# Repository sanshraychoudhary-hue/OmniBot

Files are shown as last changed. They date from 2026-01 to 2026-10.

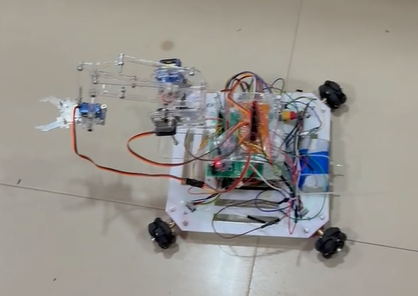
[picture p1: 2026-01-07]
assets/botimage.png

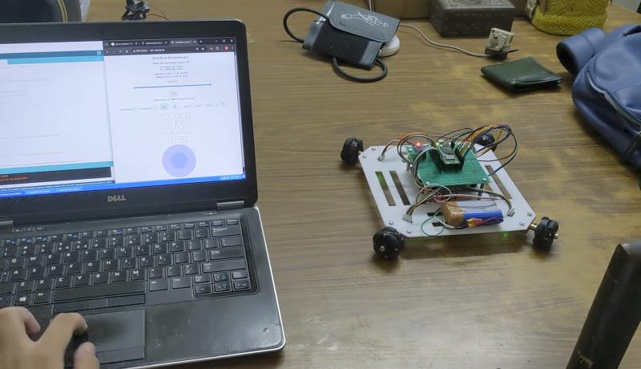
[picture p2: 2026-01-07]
assets/1.jpeg

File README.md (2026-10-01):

# OmniServe

**Project Title**: Design and Implementation of an Autonomous Holonomic Mobile Robot for Precision Warehouse Operations

## Overview
**OmniServe** is a Wi-Fi-controlled omni-directional robotic platform designed for enhanced mobility and object manipulation in constrained environments. It features precise movement using encoder feedback, a 3-DOF robotic arm for pick-and-place operations, and a web-based dashboard for real-time control, system monitoring, PID tuning, and vector-based motion commands. The robot can move in all eight directions and rotate in place, making it ideal for agile navigation. Using a PID algorithm, it achieves accurate linear movements with control over distance and direction. OmniServe is suitable for applications such as warehouse automation, smart delivery systems, and educational robotics.

This project was developed as part of a summer internship at **AICTE IDEA Lab, Guru Gobind Singh Indraprastha University**, from June 23, 2024, to August 1, 2024.

## Repository Structure
This repository contains all the design and source files for OmniServe, organized as follows:

*   **[`hardware/`](hardware/README.md)**: Specifications for motor drivers, encoders, RP2040, and wiring.
*   **[`code/`](code/README.md)**: Firmware for the Raspberry Pi Pico W (Arduino C++).
*   **[`design/`](design/README.md)**: Laser-cut chassis files (`.dxf`).
*   **[`UI/`](UI/README.md)**: Web Dashboard HTML/JS files.
*   **[`simulator_scripts/`](simulator_scripts/README.md)**: Python kinetics simulators.
*   **[`test_files/`](test_files/README.md)**: Unit tests for individual components.
*   **[`report/`](report/README.md)**: Full project report, presentation, and research.
*   **[`assets/`](assets/README.md)**: Images and demonstration videos.

---

## Features
*   **Omni-Directional Movement**: 360-degree movement in any direction, including rotation in place, enabled by omni-wheels.
*   **Encoder Feedback**: Real-time position and speed monitoring using quadrature encoders for precise control.
*   **PID Control**: Ensures accurate distance and direction travel, with tunable parameters via the dashboard.
*   **Web Dashboard**: Responsive interface for real-time control, telemetry display, and PID tuning. Supports joystick (using NippleJS) and keyboard (WASD) input.
*   **3-DOF Robotic Arm**: Servo-based arm for basic pick-and-place tasks, controlled via PWM signals.
*   **Emergency Stop**: Safety feature for immediate halt, implemented in both firmware and dashboard.
*   **Telemetry**: Live display of encoder values, robot state, and diagnostics on the dashboard.
*   **Vector-Based Commands**: Allows precise control over direction and distance.
*   **Expandable Design**: Ready for additional sensors like IMU or cameras.

### Feature Summary Table
| Feature | Description |
| :--- | :--- |
| **Omni-directional drive** | Move in any direction, rotate in place |
| **Encoder feedback** | Accurate distance and speed measurement |
| **PID control** | Precise movement and stopping |
| **Web dashboard** | Real-time control and monitoring |
| **Robotic arm** | 3-DOF, pick-and-place tasks |
| **Emergency stop** | Safety for users and environment |
| **Telemetry** | Live data on dashboard |
| **Expandable** | Add sensors and modules |

## Applications
*   **Warehouse Automation**: Material movement and inventory management in narrow aisles.
*   **Smart Delivery**: Last-mile delivery in controlled environments.
*   **Factory Logistics**: Transporting parts and tools.
*   **Educational Robotics**: Platform for teaching robotics, control systems, and programming.
*   **Prototyping**: Base for research and development in automation.

### Example Use Case: OmniServe in a Smart Warehouse
OmniServe can autonomously navigate narrow aisles, retrieve packages using its robotic arm, and deliver them to specified locations. Operators monitor via the dashboard and adjust PID parameters dynamically for varying payloads. It supports obstacle avoidance, route re-planning, and multi-robot collaboration.

## Hardware Architecture

### Chassis and Mechanical Design
*   **Four-wheel omni-wheel chassis** for 360-degree movement.
*   **Frame**: Lightweight aluminum for strength and portability.
*   **Omni-wheels**: 1.5-inch diameter for smooth lateral and diagonal movement.

### Motors and Drivers
*   **Motors**: Four DC motors, each with a magnetic quadrature encoder.
*   **Drivers**: Dual **TB6612FNG** motor drivers are used. Each driver controls two motors.
    *   **Driver 1 (Front)**: Controls Motor A (Front Left) and Motor B (Front Right).
    *   **Driver 2 (Rear)**: Controls Motor C (Rear Left) and Motor D (Rear Right).

### Encoders
*   **Quadrature encoders** (520 ticks/rev) on each wheel for closed-loop PID control and accurate distance estimation.

### Robotic Arm
*   **3-DOF servo-based arm** mounted on the chassis.
*   **Servos**: Standard hobby servos for base rotation, shoulder, and gripper movement.
*   **Capabilities**: Pick-and-place operations for objects up to 200g.

### Power Supply
*   Rechargeable **Li-ion battery pack** with voltage regulation for stable operation of logic and motors.

### Detailed Connection Diagram (GPIO Mapping)

#### Motor Driver 1 (Front Motors)
Controls the Front Left and Front Right wheels.
*   **Standby (STBY)**: GP8 (Shared)
*   **Channel A (Front Left - Motor A)**
    *   IN1: GP2
    *   IN2: GP3
    *   PWM: GP4
    *   *Encoder*: A (GP16), B (GP17)
*   **Channel B (Front Right - Motor B)**
    *   IN1: GP5
    *   IN2: GP6
    *   PWM: GP7
    *   *Encoder*: A (GP18), B (GP19)

#### Motor Driver 2 (Rear Motors)
Controls the Rear Left and Rear Right wheels.
*   **Standby (STBY)**: GP8 (Shared)
*   **Channel A (Rear Left - Motor C)**
    *   IN1: GP10
    *   IN2: GP11
    *   PWM: GP12
    *   *Encoder*: A (GP20), B (GP21)
*   **Channel B (Rear Right - Motor D)**
    *   IN1: GP13
    *   IN2: GP14
    *   PWM: GP15
    *   *Encoder*: A (GP22), B (GP26)

#### Other Connections
| Function | Pico W Pin(s) |
| :--- | :--- |
| **Standby** | GP8 |
| **Robotic Arm PWM** | GP23, GP24, GP25 (suggested) |
| **I2C (OLED/MPU)** | GP0 (SDA), GP1 (SCL) |

### Main Components Summary
| Module | Description |
| :--- | :--- |
| **Controller** | Raspberry Pi Pico W, runs main logic and hosts web dashboard |
| **Motor Drivers** | TB6612FNG, controls four DC motors |
| **Encoders** | Quadrature, provides feedback for PID control |
| **Robotic Arm** | 3-DOF, servo-based, for object manipulation |
| **Web Dashboard** | HTML/JS interface for control and monitoring |
| **Power Supply** | Li-ion battery, voltage regulation for stable operation |

### Design Choices and Trade-offs
*   **Omni-wheels** provide maximum maneuverability but require precise control logic.
*   **Raspberry Pi Pico W** selected for Wi-Fi capability and high GPIO count.
*   **Power management** ensures long operational time and safe charging.

## Software Architecture

### Embedded Firmware
*   Implemented in **Arduino C++** on Raspberry Pi Pico W.
*   Handles motor control, encoder feedback, PID computation, and dashboard communication.

### Web Dashboard
*   Responsive interface using **HTML, CSS, and JavaScript**.
*   Served directly from the Pico W.
*   **Features**: Joystick input (NippleJS), keyboard control (WASD), real-time telemetry, PID tuning.

### Communication Protocols
*   **WebSocket**: For low-latency, real-time control and telemetry.
*   **HTTP/REST**: For configuration and status queries.

### Control Logic
*   Supports direct (WASD) and vector-based movement.
*   Encoder feedback closes the loop for precise distance and direction.
*   PID controller tunable in real-time from the dashboard.

#### PID Implementation Example
```cpp
float error = target - measured;
integral += error * dt;
derivative = (error - prev_error) / dt;
output = Kp * error + Ki * integral + Kd * derivative;
prev_error = error;
```

### Encoder Handling
Interrupts are used for accurate tick counting at high speeds.

### Safety Features
Emergency stop validation for all commands.

## Methodology and Development Process
The project followed an iterative approach:
1.  **Design Phase**: Requirements analysis, block diagrams, and schematics.
2.  **Prototyping**: Breadboard testing of motors, encoders, and arm; 3D-printed parts.
3.  **Integration**: Full chassis assembly, wiring, and subsystem connection.
4.  **Testing and Validation**: Scenarios for movement, rotation, pick-and-place; accuracy checks.
5.  **Iterative Refinement**: Regular logging and addressing of issues.

### Project Timeline (Gantt Chart Overview)
Tasks were prioritized as Critical (Red), High (Orange), Medium (Yellow), Low (Blue):
*   Component Selection & BOM (Low)
*   Chassis Assembly & Wiring (Critical)
*   Motor & Power Integration (Critical)
*   Wi-Fi Setup & Web UI (Medium)
*   Encoder Calibration (High)
*   Motion Control (Critical)
*   PID Tuning & Distance Control (High)
*   Robotic Arm Mounting (High)
*   Pick-and-Place Logic (High)
*   Final Testing (Critical)
*   Documentation & Demo Video (Low)

Core functionality was built first, followed by precision control and arm integration.

## Results and Performance
*   **Movement Accuracy**: Average positional error <1 cm over 2 meters.
*   **Dashboard Latency**: <100 ms for responsive operation.
*   **Limitations**: Battery life under heavy load; occasional Wi-Fi dropouts in congested environments.

### Accuracy Table
| Target Distance (cm) | Measured (cm) | Error (cm) |
| :--- | :--- | :--- |
| 50 | 49.5 | 0.5 |
| 100 | 99.2 | 0.8 |
| 200 | 199.1 | 0.9 |

### Robotic Arm Performance
Successful pick-and-place for up to **200g** objects; repeatability within **2 mm**.

## Challenges and Solutions
| Challenge | Solution |
| :--- | :--- |
| **Omni-wheel control** | PID tuning, speed calibration |
| **Encoder noise** | Software debouncing, filtering |
| **Power management** | Separate power rails, voltage regulation |
| **Chassis alignment** | Precision assembly, iterative testing |
| **Servo mounting** | Custom 3D-printed brackets |
| **Real-time communication** | WebSocket optimization, error handling |
| **Dashboard responsiveness** | Efficient JS, minimal data transfer |
| **Subsystem integration** | Modular design, staged integration |
| **Testing in real environments** | Adaptive code, robust error handling |

## Future Work
*   **IMU Integration**: For angle feedback and stabilization.
*   **Camera and AI**: Object detection and visual navigation.
*   **Path Planning**: Autonomous navigation using map grids.
*   **Gripper Sensing**: Force or proximity sensors for delicate handling.
*   **Autonomous Object Sorting**: Algorithms for logistics applications.
*   **Research and Commercial Potential**: Platform for further development in warehouse automation, smart delivery, and education.

## Installation and Setup

### Hardware Setup
1.  Assemble the chassis with omni-wheels and mount the motors.
2.  Connect motor drivers (TB6612FNG) to the Raspberry Pi Pico W per GPIO mapping.
3.  Attach encoders to each wheel.
4.  Mount the 3-DOF robotic arm and connect servos.
5.  Wire the power supply with voltage regulation.
6.  Ensure all connections are secure and test for shorts.

### Software Setup
1.  Install Arduino IDE and add support for Raspberry Pi Pico.
2.  Upload the firmware (Arduino C++) from the `code/` directory to the Pico W.
3.  Host the web dashboard files on the Pico W (embedded in the code).
4.  Connect to the Pico W's Wi-Fi network.
5.  Access the dashboard via a web browser (e.g., `http://192.168.4.1` or the IP displayed on OLED).

### Dependencies
*   **Arduino C++** for firmware.
*   **HTML/CSS/JavaScript** for dashboard (NippleJS for joystick).
*   No additional package installations required beyond standard Arduino setup.

## Usage
1.  Power on the robot and connect to its Wi-Fi network.
2.  Open the web dashboard in a browser.
3.  Use **joystick** or **WASD keys** for movement.
4.  Tune **PID parameters** (Kp, Ki, Kd) via sliders.
5.  Control the **robotic arm** with dedicated buttons/sliders.
6.  Monitor **telemetry** (encoder values, speed, position).
7.  Activate **emergency stop** if needed.
8.  **Vector-based control**: Input direction (angle) and distance; the robot will execute precisely using PID.

## Contributors
*   **Alay Singh Negi**
*   **Kaustubh Singh Rautela**
*   **Shiven Pundir**
*   **Sanshray Choudhary**

*University School of Information, Communication & Technology (USIC&T), GGSIPU.*



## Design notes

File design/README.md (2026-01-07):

# Design Files

This directory contains the CAD and design files for the OmniBot chassis and manipulator arm.

## Files
*   `arm1plate.dxf`: Laser cutting file for the robotic arm base plate.
*   `designArm.dxf`: Laser cutting file for the arm structural components.

## Fabrication
These files are designed for laser cutting (typically Acrylic or MDF).

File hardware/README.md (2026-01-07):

# OmniBot Hardware Documentation

## Overview
The OmniBot is an autonomous holonomic mobile robot designed for precision warehouse operations. It uses a 4-wheel omnidirectional drive system (X-drive configuration) powered by a Raspberry Pi Pico W.

## Components List

### Microcontroller
*   **Raspberry Pi Pico W**: Dual-core ARM Cortex M0+ processor with built-in Wi-Fi. Handles all motor control, kinematics, sensor fusion, and web server for UI.

### Actuation & Drive
*   **Motors**: 4x DC Gear Motors with Magnetic Encoders (High precision for odometry).
*   **Motor Drivers**: 2x TB6612FNG Dual Motor Driver Carriers.
    *   *Note*: L298N was considered but TB6612FNG was chosen for better efficiency and compact size.
*   **Wheels**: 4x Omni-directional wheels (38mm diameter). The rollers allow sideways movement.

### Sensors
*   **Encoders**: 4x Incremental Quadrature Encoders (attached to motors) - 520 ticks/revolution.
*   **IMU**: MPU6050 (Accelerometer + Gyroscope) for orientation tracking (optional/integrated in some code versions).

### Interface
*   **Display**: OLED Display (0.96" 128x64 I2C) for status messages, IP address, and mode display.
*   **Joystick**: Analog Joystick (for manual control in some test setups).

## Pinout Configuration (Raspberry Pi Pico W)

| Component | Pin Function | Pico GP Pin |
| :--- | :--- | :--- |
| **Motor A (Front Left)** | IN1 | GP2 |
| | IN2 | GP3 |
| | PWM | GP4 |
| | Enc A | GP16 |
| | Enc B | GP17 |
| **Motor B (Front Right)** | IN1 | GP5 |
| | IN2 | GP6 |
| | PWM | GP7 |
| | Enc A | GP18 |
| | Enc B | GP19 |
| **Motor C (Rear Left)** | IN1 | GP10 |
| | IN2 | GP11 |
| | PWM | GP12 |
| | Enc A | GP20 |
| | Enc B | GP21 |
| **Motor D (Rear Right)** | IN1 | GP13 |
| | IN2 | GP14 |
| | PWM | GP15 |
| | Enc A | GP22 |
| | Enc B | GP26 |
| **Drivers** | STBY | GP8 |
| **I2C (Display/MPU)** | SDA | (Check Code) |
| | SCL | (Check Code) |

## Kinematics
The robot uses a 4-wheel X-configuration. The wheels are mounted at 45, 135, 225, and 315 degrees relative to the chassis frame.
*   **Wheel Angles**: [45°, 135°, 225°, 315°]
*   **Kinematic Model**: Allows calculation of individual wheel speeds based on desired Forward (Vx), Strafe (Vy), and Rotational (ω) velocities.

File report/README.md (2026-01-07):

# Project Report & Documentation

This directory contains the formal documentation, research resources, and presentation materials.

## Files
*   `omniBotReport.pdf`: The complete comprehensive project report.
*   `GeometricApproachtoInverseKinematics.pdf`: Reference paper for the 3-DOF arm implementation.
*   `presentation_outline.txt`: Outline used for the final presentation.
*   `research_and_resources.txt`: Notes on research topics (kinematics, components) and learning resources.
*   `canva_presentation_instructions.txt`: (Internal) Notes for slide creation.

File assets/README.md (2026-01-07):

# Project Assets

This folder contains media and visual assets for the OmniBot project.

## Contents
*   **Images**: Photos of the robot (`1.jpeg`), diagrams (`block diagram.png`, `softwareFlowchart.png`), and generated visualizations.
*   **Videos**: Demonstration videos of the robot in action (`Bot1.mp4`, `Bot2.mp4`, `OmniServe.mp4`).
*   **Graphics**: Logos and presentation materials.

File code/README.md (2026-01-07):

# OmniBot Code

This directory contains the firmware for the Raspberry Pi Pico W.

## Main Firmware
The active and most recent firmware version is located in the **`picoOmniCAR_latest_noMPU_oled_SavedWifi_P1`** directory.

### Features
*   **Omnidirectional Control**: Implements vector-based kinematics for holonomic movement.
*   **Wi-Fi Control**: Hosts a web server (or connects to one) to receive commands from the Web UI.
*   **PID Control**: (If applicable in this version) uses encoder feedback to maintain precise motor speeds.
*   **OLED Feedback**: Displays connection status, IP address, and current state.

## Legacy / Reference
*   `legacy_working_cursor.ino`: An older, known-working version of the code that supports cursor control and MPU6050 integration.

## Dependencies
This project is built using the Arduino IDE (with RP2040 core) or PlatformIO.
Required Libraries (install via Library Manager):
*   **Adafruit SSD1306** (for OLED)
*   **Adafruit GFX** (for OLED)
*   **Adafruit MPU6050** (if using MPU version)
*   **Adafruit Unified Sensor**
*   **WiFi** (Standard Pico W library)

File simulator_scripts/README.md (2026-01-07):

# Simulator Scripts

Python scripts for simulating the kinematics and behavior of the OmniBot.

## Files
*   `omni_bot_simulator.py`: Main simulation script.
*   `omni_sim.py`: Kinematics module used to calculate wheel ticks and trajectories.

## Requirements
*   Python 3.x
*   NumPy (`pip install numpy`)
*   Matplotlib (likely required for plotting in `omni_bot_simulator.py`)

## Usage
Run the simulator to visualize path planning and kinematic equations before deploying to the real robot.
```bash
python omni_bot_simulator.py
```

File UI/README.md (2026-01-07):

# Web UI

This directory contains the user interface for controlling the OmniBot.

## Files
*   `ui.html`: A standalone HTML/JS dashboard control panel.

## Usage
1.  Connect your device to the same Wi-Fi network as the OmniBot (or the OmniBot's Hotspot).
2.  Open `ui.html` in a modern web browser (Chrome, Firefox, Edge).
3.  Enter the IP address displayed on the OmniBot's OLED screen into the UI connection field.
4.  Use the on-screen joystick or buttons to control the robot.

## Features
*   **Virtual Joystick**: For omnidirectional manual control.
*   **Status Indicators**: Shows connection health.

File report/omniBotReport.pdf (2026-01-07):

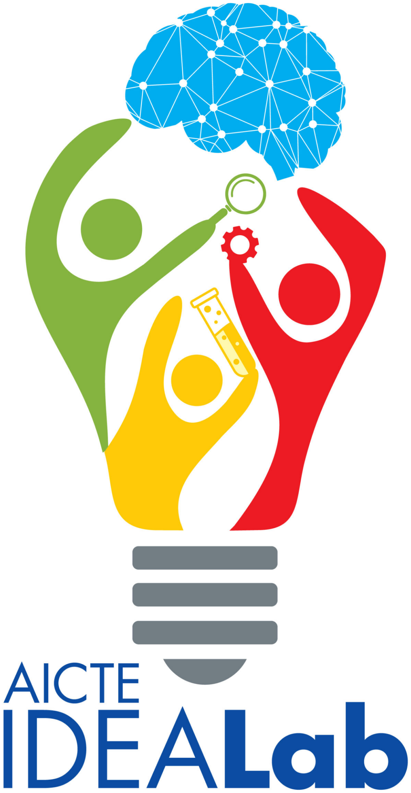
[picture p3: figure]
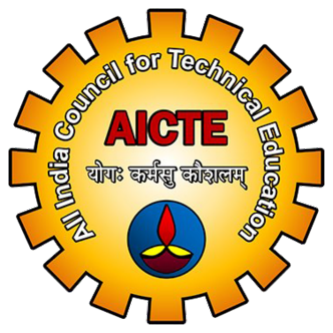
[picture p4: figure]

## Summer Internship Report

on

## OmniServe: Wi-Fi Controlled Omni-Directional Robot with Encoder Feedback and Pick-and-Place Arm

### Duration: June 23, 2024 to August 1, 2024

Under Supervision Of
Prof. Shiv Ram Meena
Mr. Saurabh Anand

Submitted By:
Alay Singh Negi 00916412823 Shiven Pundir 01716412823
Sanshray Choudhary 00816412823 Kaustubh Singh Rautela 00216412823 Jaideep 06416412823
Deependu Sharma 00616412823 Paras 05716412823
Divyansh 05916412823

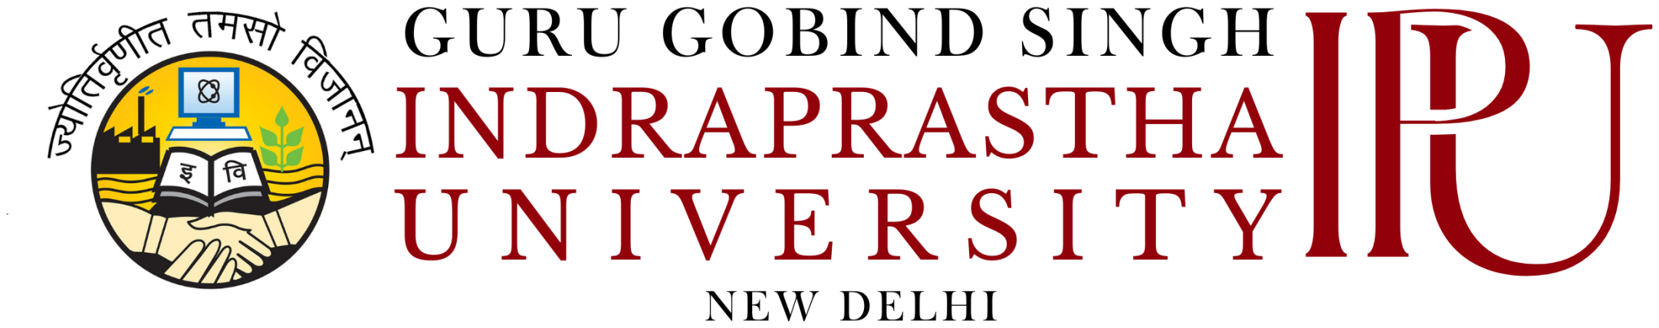
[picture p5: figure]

AICTE IDEA Lab-Guru Gobind Singh Indraprastha University E-Block, Guru Gobind Singh Indraprastha University Sector-16C, Dwarka, New Delhi - 110078 July 2024

### Certificate

This is to certify that the internship project entitled “OmniServe: Wi-Fi Controlled Omni-Directional Robot with Encoder Feedback and Pick-and-Place Arm” was successfully completed by the following students in partial fulfillment of the requirements for the award of the degree of Bachelor of Technology (ECE) under the internship program at AICTE IDEA Lab-Guru Gobind Singh Indraprastha University, New Delhi
- 110078.
1. Alay Singh Negi
2. Shiven Pundir
3. Sanshray Choudhary
4. Kaustubh Singh Rautela
5. Jaideep
6. Deependu
7. Paras
8. Divyansh
Mentor | Mentor

### Declaration

We hereby declare that the project work presented in this internship report entitled “OmniServe: Wi-Fi Controlled Omni-Directional Robot with Encoder Feedback and Pick-and-Place Arm” is entirely our own work and has not been submitted for any degree or diploma from this or any other institute for partial fulfillment of the requirements for the award of the degree of Bachelor of Technology (ECE).

1. Alay Singh Negi | USIC&T, GGSIPU
2. Shiven Pundir | USIC&T, GGSIPU
3. Sanshray Choudhary | USIC&T, GGSIPU
4. Kaustubh Singh Rautela | USIC&T, GGSIPU
5. Jaideep | USIC&T, GGSIPU
6. Deependu | USIC&T, GGSIPU
7. Paras | USIC&T, GGSIPU
8. Divyansh | USIC&T, GGSIPU

### Acknowledgment

We would like to express our sincere gratitude to the University School of Information, Communication & Technology, Guru Gobind Singh Indraprastha University for providing us with the valuable opportunity to participate in this internship program. Their constant encouragement and academic environment have played a vital role in our learning and professional development.
We are also deeply thankful to the AICTE IDEA Lab – Guru Gobind Singh Indraprastha University, located at E-Block, Sector 16C, Dwarka, New Delhi – 110078, for organizing the internship and enabling us to be part of such an enriching experience. The knowledge and hands-on exposure gained during this internship have been immensely beneficial to our growth.
A special note of thanks to our mentor, Prof. Shiv Ram Meena, for his unwavering support, insightful guidance, and constructive feedback throughout the project. His mentorship was instrumental in shaping our understanding and execution of this work.
We would also like to sincerely thank Ms. Heena Kalim, whose constant support and encouragement were crucial to our progress. Her sessions helped us understand a variety of tools and how to effectively use them in real-world applications. Her approachable nature and clarity in teaching made complex topics accessible and actionable.
Lastly, we extend our gratitude to all the faculty members whose teachings and support have contributed significantly to our academic journey.

### Abstract

This project presents OmniServe, a Wi-Fi-controlled, omni-directional robotic platform designed for enhanced mobility and object manipulation in constrained environments. The robot features precise movement capabilities using encoder feedback and a 3-DOF robotic arm for pick-and-place operations. It can move in all eight directions and rotate in place, enabling agile navigation. A web-based dashboard facilitates real-time control, system monitoring, PID tuning, and vector-based motion commands. Using a PID algorithm, the robot can perform accurate linear movements with control over both distance and direction. With its integrated robotic arm, OmniServe extends its utility to applications such as warehouse automation, smart delivery systems, and educational robotics.

# Contents

Introduction | 7
Literature Survey | 9
System Overview | 10
Hardware Architecture | 12
Software Architecture | 14
Methodology | 16
Features and Applications | 18
Results and Discussion | 20
Challenges Faced | 22
Future Work | 24
Conclusion | 25
1 Bibliography | 26

# Introduction

### Motivation

The rapid advancement of automation and robotics has revolutionized industries, logistics, and daily life. However, the need for versatile, precise, and remotely controllable robots remains a significant challenge, especially in constrained environments such as warehouses and smart factories. OmniServe was conceived to address these challenges by providing a robust, omni-directional robotic platform with advanced feedback and manipulation capabilities.

### Problem Statement

Traditional mobile robots are often limited by their drive mechanisms, restricting their movement to forward, backward, and simple turns. This limitation hinders their effectiveness in environments requiring agile navigation and precise positioning. Additionally, the lack of real-time feedback and manipulation capabilities further restricts their utility in complex tasks such as pick-and-place operations.

### Objectives

The primary objectives of the OmniServe project are:

- To design and develop a Wi-Fi controlled omni-directional robot capable of 360-degree movement.
- To implement encoder feedback for precise distance and direction control.
- To integrate a 3-DOF robotic arm for pick-and-place operations.
- To develop a web-based dashboard for real-time control, monitoring, and PID tuning.
- To demonstrate the robot’s applicability in warehouse automation, smart delivery, and educational robotics.

### Report Structure

This report is organized as follows:

- Literature Survey: Reviews related work and existing technologies in omni-directional robotics and feedback systems.
- System Overview: Provides a high-level description of the hardware and software components.
- Hardware and Software Architecture: Details the design and implementation of the robot’s physical and control systems.
- Methodology: Describes the development process, including design, prototyping, and testing.
- Features and Applications: Highlights the key features and potential use cases of OmniServe.
- Results and Discussion: Presents experimental results, performance analysis, and insights gained.
- Challenges Faced: Discusses obstacles encountered and solutions implemented.
- Future Work: Outlines possible enhancements and research directions.
- Conclusion: Summarizes the project outcomes and its significance.

# Literature Survey

### Omni-Directional Robots

Omni-directional robots have been widely researched for their ability to move in any direction without changing orientation, making them ideal for applications in constrained environments. Mecanum and omni-wheel designs are commonly used to achieve this mobility [1, 2].

### Encoder Feedback and PID Control

Precise movement in mobile robots is often achieved using quadrature encoders and PID (Proportional-Integral-Derivative) control algorithms. Encoder feedback allows for accurate distance and speed measurement, while PID controllers help maintain desired trajectories [3, 4].

### Robotic Arms and Manipulation

Robotic arms with multiple degrees of freedom (DOF) are essential for pick-and-place tasks. The integration of servo motors and inverse kinematics enables precise object manipulation [5, 6].

### Web-Based Control Systems

Recent advancements in IoT and embedded systems have enabled real-time robot control via web interfaces. Technologies such as WebSockets and REST APIs facilitate seamless communication between users and robots [7, 8].

### Summary

The literature indicates that combining omni-directional mobility, encoder feedback, PID control, and web-based interfaces can significantly enhance the versatility and usability of mobile robots in industrial and educational settings.

# System Overview

### System Architecture

OmniServe is designed as a modular, Wi-Fi controlled omni-directional robot with encoder feedback and a 3-DOF robotic arm. The system is divided into several subsystems: drive, feedback, control, and manipulation.

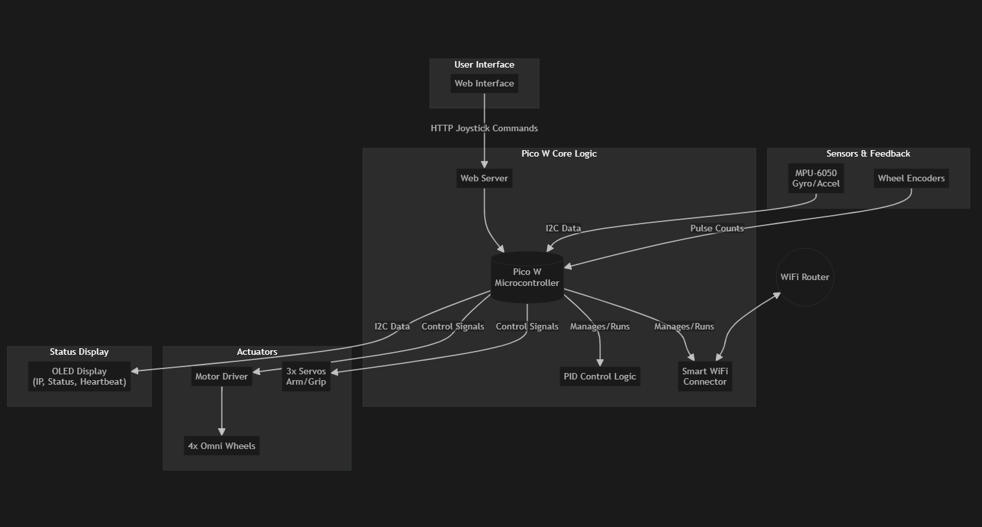
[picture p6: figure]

Figure 1: Block diagram of the OmniServe system.

### Main Components

- Controller: Raspberry Pi Pico W for main control and Wi-Fi communication.
- Motors: Four DC motors with omni-wheels for 360-degree movement.
- Motor Drivers: Dual TB6612FNG drivers for efficient motor control.
- Encoders: Quadrature encoders on each wheel for feedback.
- Robotic Arm: 3-DOF servo-based arm for pick-and-place tasks.
- Web Dashboard: Real-time control and monitoring interface.
- Power Supply: Battery pack with voltage regulation.

### Module Summary

Module | Description
Controller | Raspberry Pi Pico W, runs main logic and hosts web dashboard
Motor Drivers | TB6612FNG, controls four DC mo-tors
Encoders | Quadrature, provides feedback for PID control
Robotic Arm | 3-DOF, servo-based, for object ma-nipulation
Web Dashboard | HTML/JS interface for control and monitoring
Power Supply | Li-ion battery, voltage regulation for stable operation

### Interaction

The controller receives commands from the web dashboard, processes encoder feedback, and drives the motors accordingly. The robotic arm is controlled via PWM signals, and all telemetry is sent back to the dashboard for real-time monitoring.

# Hardware Architecture

### Chassis and Mechanical Design

The robot uses a four-wheel omni-wheel chassis, enabling movement in any direction. The frame is constructed from lightweight aluminum for strength and portability. The omni-wheels (1.5-inch diameter) allow for smooth lateral and diagonal movement.

### Motors and Drivers

Four DC motors are used, each controlled by a TB6612FNG dual motor driver. The drivers are chosen for their efficiency, compactness, and ability to handle the required current.

### Encoders

Each wheel is equipped with a quadrature encoder (520 ticks/rev) for precise feedback. The encoders are essential for closed-loop PID control and accurate distance estimation.

### Robotic Arm

A 3-DOF servo-based arm is mounted on the chassis. The arm uses standard hobby servos for base rotation, shoulder, and gripper movement, allowing for basic pick-and-place operations.

### Power Supply

A rechargeable Li-ion battery pack powers the system, with voltage regulation to ensure stable operation for both logic and motors.

### Wiring and Integration

All components are connected to the Raspberry Pi Pico W. Careful wiring and cable management ensure reliability and ease of maintenance.

### GPIO Mapping

Function | Pico W Pin(s)
Motor Control | GP2–GP15
Encoder Inputs | GP16–GP22, GP26
Standby | GP8
Robotic Arm PWM | GP23, GP24, GP25 (suggested)
I2C (reserved) | GP0 (SDA), GP1 (SCL)

### Hardware Photo

Figure 2: OmniServe hardware prototype.

### Design Choices and Trade-offs

The use of omni-wheels provides maximum maneuverability but requires careful control logic. The Raspberry Pi Pico W was selected for its Wi-Fi capability and GPIO count. Power management was a key consideration to ensure long operational time and safe charging.

# Software Architecture

### Embedded Firmware

The core logic is implemented in Arduino C++ and runs on the Raspberry Pi Pico W. The firmware handles motor control, encoder feedback, PID computation, and communication with the web dashboard.

### Web Dashboard

A responsive web dashboard (HTML, CSS, JavaScript) is served from the Pico W. It provides real-time control, telemetry, and PID tuning. Joystick input is handled using NippleJS, and all commands are sent via WebSockets.

### Communication Protocols

- WebSocket: For low-latency, real-time control and telemetry.
- HTTP/REST: For configuration and status queries.

### Control Logic

The robot supports both direct (WASD) and vector-based movement. Encoder feedback is used to close the loop for precise distance and direction control. The PID controller is tuned in real time from the dashboard.

### PID Implementation

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

### Encoder Handling

Interrupts are used to read quadrature encoder signals, ensuring accurate tick counting even at high speeds.

### Safety Features

An emergency stop is implemented in both firmware and dashboard. All commands are validated for safety before execution.

### Software Flowchart

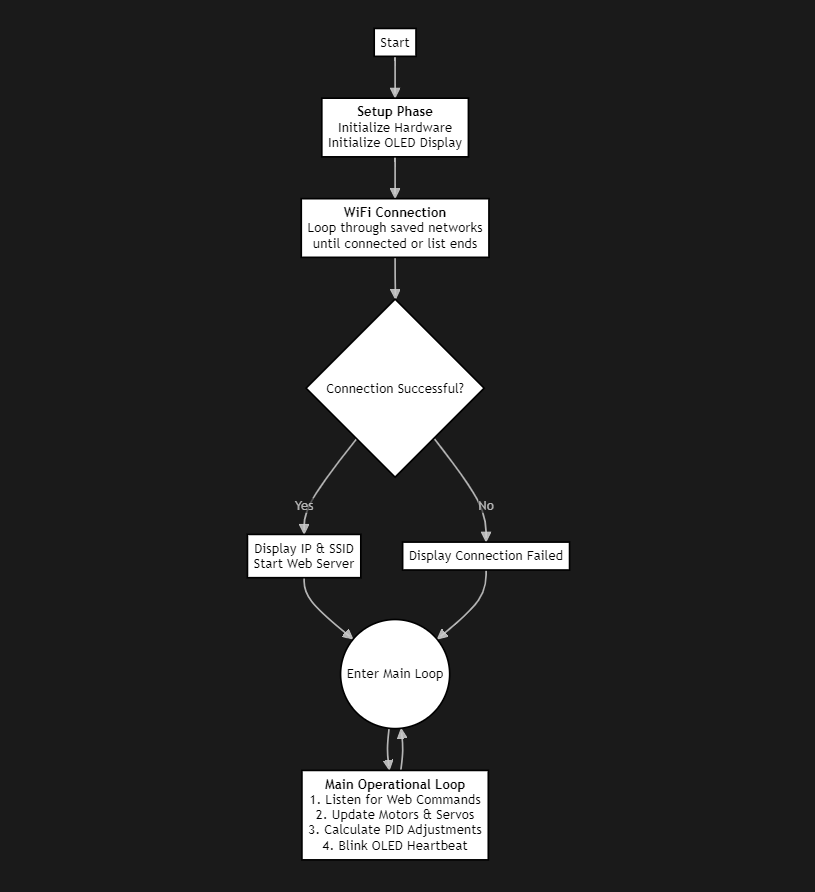
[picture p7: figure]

Figure 3: Software architecture flowchart.

# Methodology

### Design Phase

The project began with requirements analysis and system design. Block diagrams and schematics were created to plan the hardware and software integration.

### Prototyping

Initial prototypes were built using breadboards and 3D-printed parts. Motor drivers, encoders, and the robotic arm were tested individually before full integration.

### Integration

All subsystems were integrated on the main chassis. Careful attention was paid to wiring, power distribution, and signal integrity. The web dashboard was connected to the firmware for real-time control.

### Testing and Validation

The robot was tested in various scenarios: straight-line travel, diagonal movement, rotation, and pick-and-place tasks. Encoder feedback and PID control were validated for accuracy. The dashboard was tested for responsiveness and reliability.

### Iterative Development

Development followed an iterative approach, with regular testing and refinement. Issues were logged and addressed in each cycle.

### Gantt Chart

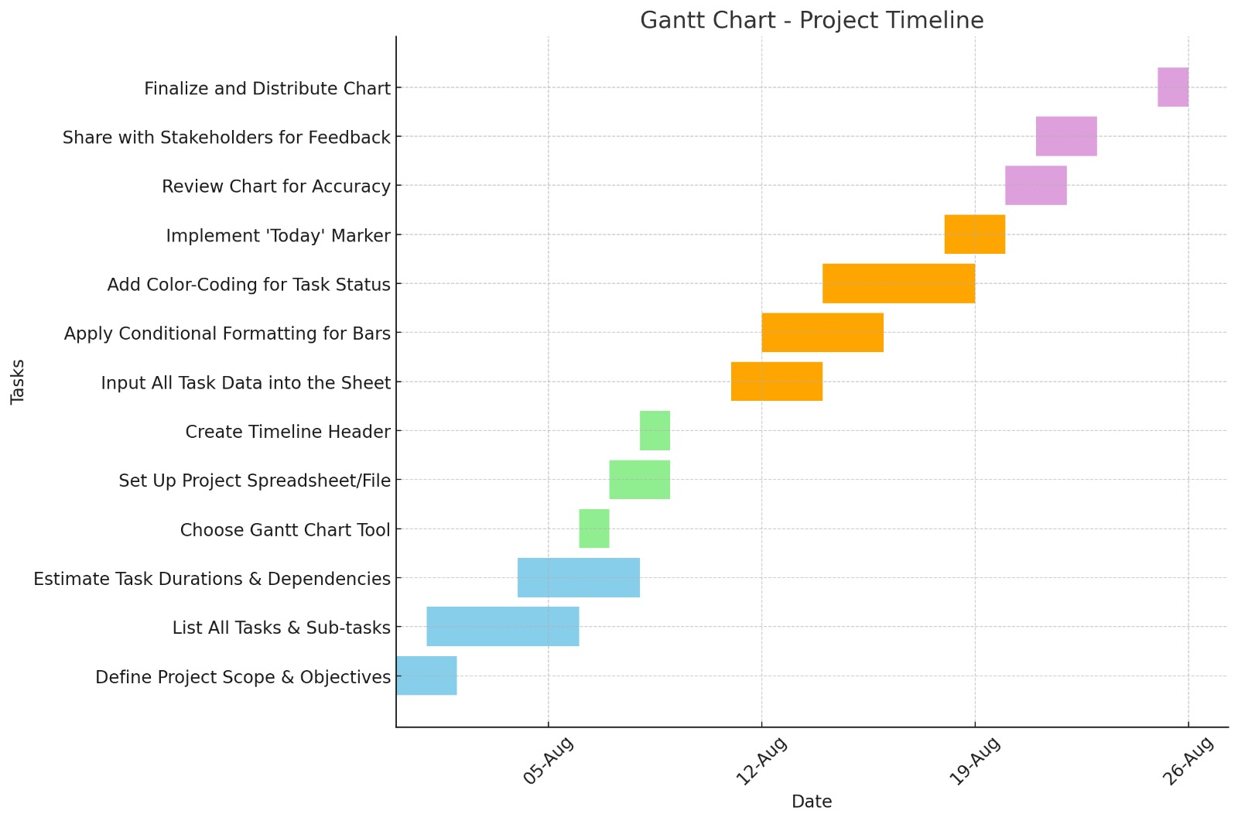
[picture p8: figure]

Figure 4: Project Gantt chart.

# Features and Applications

### Key Features

- Omni-Directional Movement: 360-degree movement in any direction, including rotation.
- Encoder Feedback: Real-time position and speed monitoring for precise control.
- PID Control: Ensures accurate distance and direction travel.
- Web Dashboard: Real-time control, telemetry, and PID tuning via Wi-Fi.
- Joystick and Keyboard Control: Supports both intuitive joystick and keyboard (WASD) input.
- 3-DOF Robotic Arm: Enables pick-and-place operations.
- Emergency Stop: Safety feature for immediate halt.
- Telemetry: Live display of encoder values, state, and diagnostics.
- Expandable: Ready for additional sensors (IMU, camera, etc.).

### Feature Summary

Feature | Description
Omni-directional drive | Move in any direction, rotate in place
Encoder feedback | Accurate distance and speed mea-surement
PID control | Precise movement and stopping
Web dashboard | Real-time control and monitoring
Robotic arm | 3-DOF, pick-and-place tasks
Emergency stop | Safety for users and environment
Telemetry | Live data on dashboard
Expandable | Add sensors and modules

### Applications

- Warehouse Automation: Material movement, inventory management.
- Smart Delivery: Last-mile delivery in controlled environments.
- Factory Logistics: Transporting parts and tools.
- Educational Robotics: Teaching robotics, control, and programming.
- Prototyping: Platform for research and development.

### Use-Case Scenario

Imagine a warehouse where OmniServe autonomously navigates aisles, picks up packages using its robotic arm, and delivers them to designated locations. The operator monitors and controls the robot remotely via the dashboard, adjusting PID parameters for optimal performance in real time.

# Results and Discussion

### Movement Accuracy

Experiments were conducted to evaluate the robot’s ability to travel set distances and angles. The encoder feedback and PID control enabled the robot to achieve an average positional error of less than 1 cm over 2 meters.

Table 4: Distance Travel Accuracy

Target Distance (cm) | Measured (cm) | Error (cm)
50 100 200 | 49.5 99.2 199.1 | 0.5 0.8 0.9

### Robotic Arm Performance

The 3-DOF arm successfully performed pick-and-place tasks with objects up to 200g. Repeatability tests showed consistent placement within 2 mm.

### Dashboard Latency

The web dashboard maintained a control latency below 100 ms, ensuring responsive operation.

### Figures


Figure 5: Test run of OmniServe .

### Discussion

The results demonstrate that OmniServe meets its design goals for mobility, precision, and manipulation. The main limitations observed were battery life under heavy load and occasional Wi-Fi dropouts in congested environments.

# Challenges Faced

### Technical Challenges

- Omni-Wheel Control: Achieving smooth, coordinated movement required careful tuning of motor speeds and PID parameters.
- Encoder Noise: Electrical noise caused false encoder readings, which were mitigated with software debouncing and filtering.
- Power Management: Balancing power between motors, servos, and logic circuits was critical to prevent brownouts.

### Hardware Challenges

- Chassis Alignment: Ensuring all wheels were perfectly aligned to avoid drift.
- Servo Mounting: Designing robust mounts for the robotic arm servos.

### Software Challenges

- Real-Time Communication: Maintaining low-latency, reliable Web-Socket connections.
- Dashboard Responsiveness: Optimizing the web interface for real-time updates.

### Integration and Testing

- Subsystem Integration: Combining hardware and software modules without conflicts.
- Testing in Real Environments: Adapting to Wi-Fi interference and variable lighting for the arm.

### Summary Table

Challenge | Solution
Omni-wheel control | PID tuning, speed calibration
Encoder noise | Software debouncing, filtering
Power management | Separate power rails, voltage regulation
Chassis alignment | Precision assembly, iterative testing
Servo mounting | Custom 3D-printed brackets
Real-time communica-tion | WebSocket optimization, error handling
Dashboard responsive-ness | Efficient JS, minimal data trans-fer
Subsystem integration | Modular design, staged integra-tion
Testing in real environ-ments | Adaptive code, robust error han-dling

# Future Work

### IMU Integration

Adding an inertial measurement unit (IMU) will enable angle feedback and stabilization, improving navigation and control.

### Camera and AI

Integrating a camera and AI module will allow for object detection, visual navigation, and advanced automation.

### Path Planning

Implementing path planning algorithms will enable the robot to autonomously navigate complex environments using map grids.

### Gripper Sensing

Upgrading the robotic arm with force or proximity sensors will improve pick-and-place reliability and enable delicate object handling.

### Autonomous Object Sorting

Developing algorithms for autonomous object sorting will expand the robot’s utility in logistics and manufacturing.

### Research and Commercial Potential

OmniServe can serve as a research platform for robotics and automation, and has potential for commercialization in warehouse automation, smart delivery, and educational robotics.

# Conclusion

OmniServe demonstrates the power of integrating omni-directional mobility, encoder feedback, PID control, and robotic manipulation into a single, Wi-Fi controlled platform. The project achieved its goals of precise movement, real-time control, and object interaction, validated through extensive testing and real-world scenarios.
The team gained valuable experience in embedded systems, robotics, software development, and teamwork. OmniServe’s modular design and open architecture make it a strong candidate for further research, educational use, and commercial deployment.
As robotics continues to transform industries, projects like OmniServe pave the way for smarter, more adaptable automation solutions. The knowledge and skills acquired will serve as a foundation for future innovation in robotics and automation.

# Bibliography

[1] M. Yim, W.-M. Shen, and B. Salemi, “Polybot: a modular reconfigurable robot,” Proceedings 2000 ICRA. Millennium Conference. IEEE International Conference on Robotics and Automation. Symposia Proceedings (Cat. No.00CH37065), pp. 514–520, 2000.
[2] B. E. Ilon, “Wheels for a course stable self-propelling vehicle moving in any desired direction on the ground,” US Patent 3876255, 1975.
[3] K. J. ˚Astr¨om and T. H¨agglund, PID Controllers: Theory, Design, and Tuning. Instrument Society of America, 1995.
[4] K. Ohnishi, “A new servo method in mechatronics,” IEEE Transactions on Industrial Electronics, vol. IE-34, no. 1, pp. 3–7, 1987.
[5] J. J. Craig, Introduction to Robotics: Mechanics and Control. Pearson Prentice Hall, 2005.
[6] B. Siciliano and O. Khatib, Springer Handbook of Robotics. Springer, 2010.
[7] A. Al-Fuqaha, M. Guizani, M. Mohammadi, M. Aledhari, and
M. Ayyash, “Internet of things: A survey on enabling technologies, protocols, and applications,” IEEE Communications Surveys Tutorials, vol. 17, no. 4, pp. 2347–2376, 2015.
[8] I. Lee and K. Lee, “The internet of things (iot): Applications, investments, and challenges for enterprises,” Business Horizons, vol. 58, no. 4, pp. 431–440, 2013.

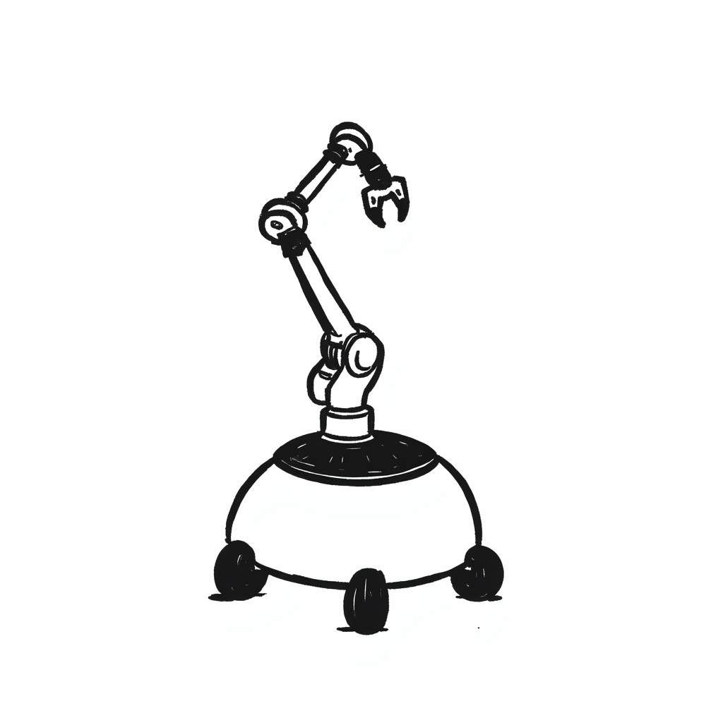
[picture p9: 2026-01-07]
assets/KWLnM13xIoRA6nbylS85tfKQQ0C2_images_a omnidirectional robot with pick and place robotic arm_ink-drawing-v2_0_1754448395945_ypl95d_1_generation.png

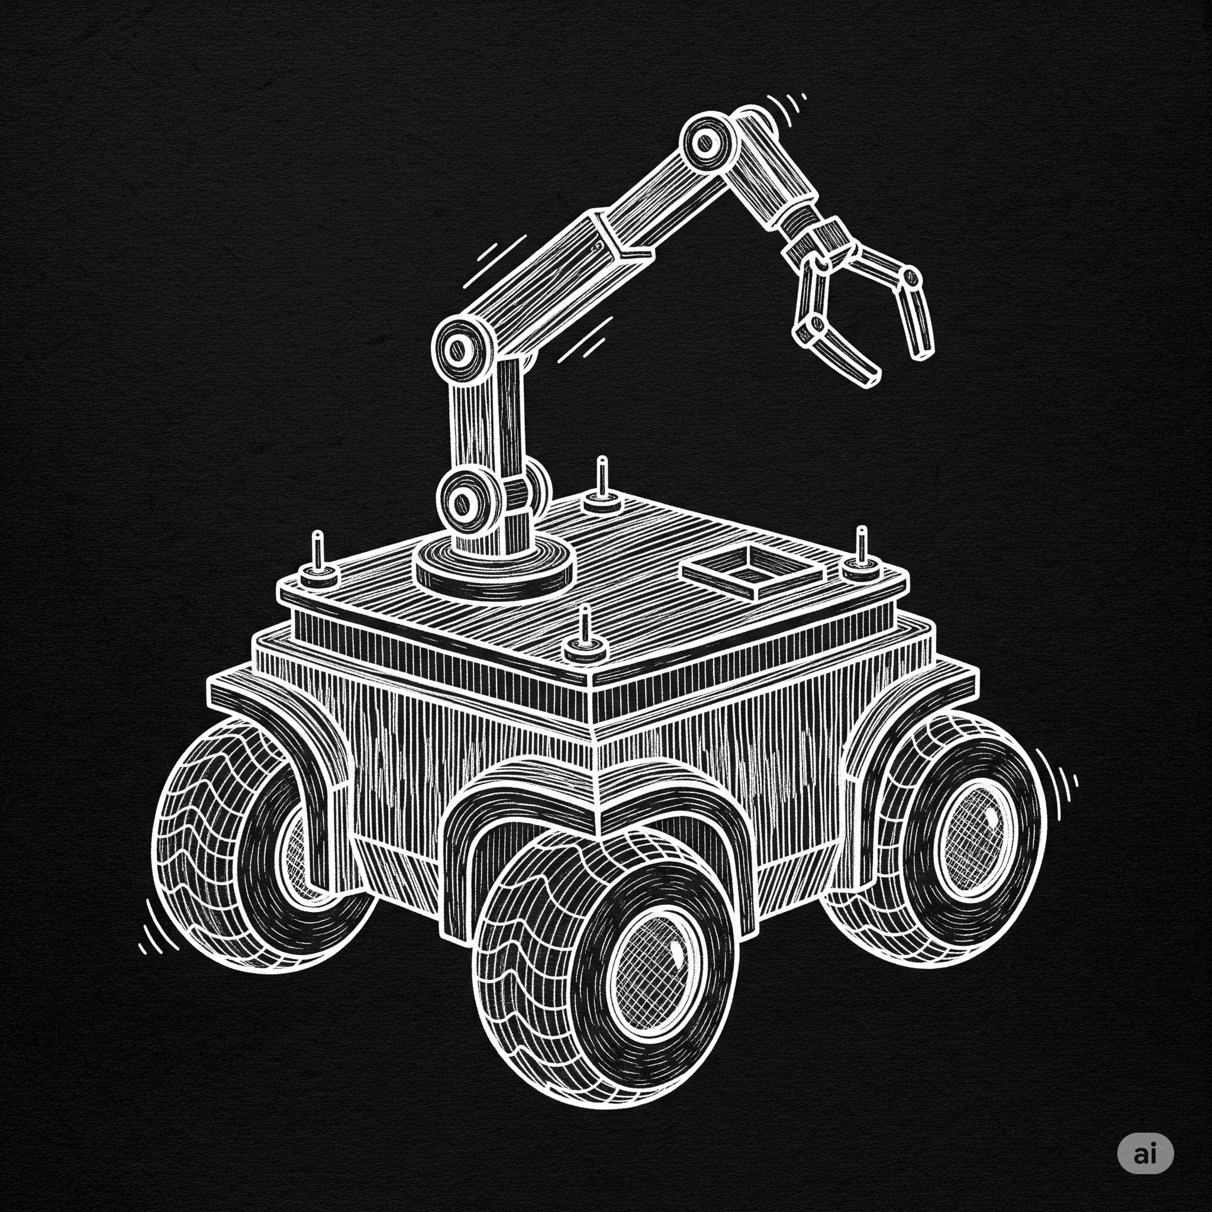
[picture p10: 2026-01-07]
assets/Gemini_Generated_Image_fljk0ffljk0ffljk.png

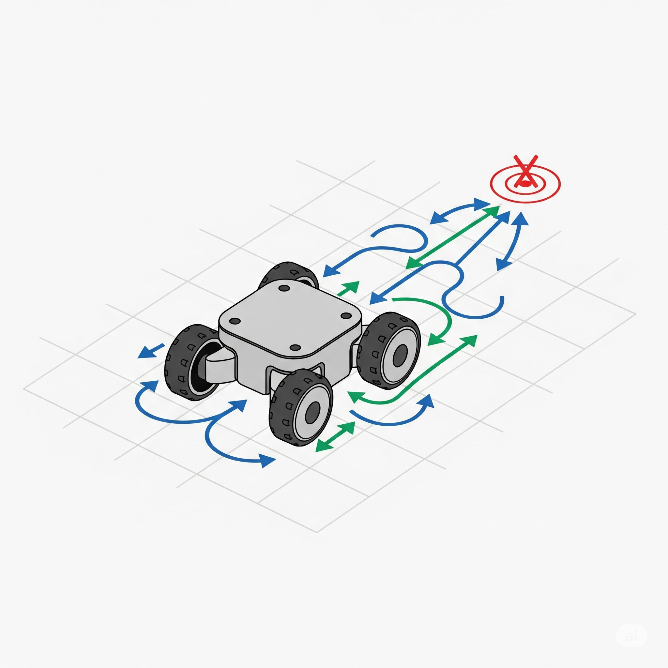
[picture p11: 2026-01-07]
assets/Gemini_Generated_Image_u47356u47356u473.png

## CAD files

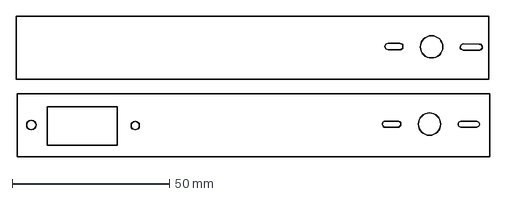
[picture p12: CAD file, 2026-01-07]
design/designArm.dxf
150.3 x 44.6 mm

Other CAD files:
design/arm1plate.dxf

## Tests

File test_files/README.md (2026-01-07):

# Test Files

This directory contains individual unit test sketches used to debug and verify specific hardware components before full integration.

## Files
*   **picoEncoderTest**: Verifies that the motor encoders are counting ticks correctly.
*   **picoMotorTest**: Tests basic motor rotation (Forward/Backward) to check driver wiring.
*   **picoDisplayTest**: Tests the OLED screen connection and library.
*   **picoMPU_test**: Reads raw data from the MPU6050 accelerometer/gyroscope.
*   **picoServoTest / picoServoTestWifi**: Tests servo motor control for the arm.
*   **picoWifiTester**: Verifies Wi-Fi connectivity on the Pico W.
*   **picoLed**: Simple blink test.

## Usage
Upload these sketches individually to isolate issues with specific components.

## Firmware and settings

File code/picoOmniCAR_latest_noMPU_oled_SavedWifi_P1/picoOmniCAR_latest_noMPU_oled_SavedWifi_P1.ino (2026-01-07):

/**********************************************************
 *                    PIN CONNECTIONS                     *
 **********************************************************

 Wi-Fi Control Bot with 4 Motors & 8 Encoder Inputs
 Controller: Raspberry Pi Pico W
 Motor Drivers: 2 x TB6612FNG (4 motors total)

 ------------------- MOTOR CONNECTIONS --------------------

 Motor A (Front Left):
   AIN1  -> GP2
   AIN2  -> GP3
   PWMA  -> GP4

 Motor B (Front Right):
   BIN1  -> GP5
   BIN2  -> GP6
   PWMB  -> GP7

 Motor C (Rear Left):
   CIN1  -> GP10
   CIN2  -> GP11
   PWMC  -> GP12

 Motor D (Rear Right):
   DIN1  -> GP13
   DIN2  -> GP14
   PWMD  -> GP15

 STBY (Standby for both drivers): 
   STBY  -> GP8

 ------------------- ENCODER CONNECTIONS ------------------

 Front Left Encoder (Motor A):
   Channel A -> GP16 (FL_ENC_A)
   Channel B -> GP17 (FL_ENC_B)

 Front Right Encoder (Motor B):
   Channel A -> GP18 (FR_ENC_A)
   Channel B -> GP19 (FR_ENC_B)

 Rear Left Encoder (Motor C):
   Channel A -> GP20 (RL_ENC_A)
   Channel B -> GP21 (RL_ENC_B)

 Rear Right Encoder (Motor D):
   Channel A -> GP22 (RR_ENC_A)
   Channel B -> GP26 (RR_ENC_B)

------------------- WHEEL SPECS ------------------
DIA = 1.5 inch
Ticks per revoultion = 520

------------------- PCB/WIRING INFO ------------------
A-B A-B A-B A-B PWM-B-A PWM-B-A PWM-B-A PWM-B-A

-------------------SERVO INFO ------------------
Base: GP9
Left Hand: GP8
Right Hand: GP27
Gripper: GP28

**********************************************************/

#include <WiFi.h>

#include <Servo.h>

#include <Wire.h>
#include <Adafruit_GFX.h>
#include <Adafruit_SH110X.h>


// Wi-Fi credentials structure
struct WiFiNetwork {
  const char* ssid;
  const char* password;
};

// List of known networks
WiFiNetwork knownNetworks[] = {
  {"SurPoon", "gogetsomehelpfromgod1234"},
  {"IDEA LAB_2.4G", "ggsipu@321"}
  };

const int numNetworks = sizeof(knownNetworks) / sizeof(knownNetworks[0]);


// Wi-Fi credentials
//const char* ssid = "SurPoon";
//const char* password = "gogetsomehelpfromgod1234";

// OLED Display for SH1106
#define OLED_I2C_ADDRESS 0x3C
#define DISPLAY_WIDTH 128
#define DISPLAY_HEIGHT 64
#define OLED_RESET -1
//#define OLED_SDA 16
//#define OLED_SCL 17
Adafruit_SH1106G display = Adafruit_SH1106G(DISPLAY_WIDTH, DISPLAY_HEIGHT, &Wire, OLED_RESET);

// -- Heartbeat Globals --
unsigned long lastHeartbeatMillis = 0;
bool heartbeatState = false;

// Wi-Fi Credentials
//const char* ssid = "IDEA LAB_2.4G";
//const char* password = "ggsipu@321";

// Motor A (Front Left)
#define AIN1 2
#define AIN2 3
#define PWMA 4

// Motor B (Front Right)
#define BIN1 6  // changed from 6 to 0
#define BIN2 5
#define PWMB 7  // changed from 7 to 1

// Motor C (Rear Left)--- swapped for direction change
#define CIN1 10
#define CIN2 11
#define PWMC 12

// Motor D (Rear Right)--- swapped for direction change
#define DIN1 14
#define DIN2 13
#define PWMD 15

//#define STBY 8
//#define LED_PIN 25



// --------- Encoder Pin Definitions ---------
#define FL_ENC_A 0 // 16
#define FL_ENC_B 1 // 17
#define FR_ENC_A 19
#define FR_ENC_B 18
#define RL_ENC_A 22
#define RL_ENC_B 26
#define RR_ENC_A 21
#define RR_ENC_B 20

// --------- Encoder Tick Counters (Signed) ---------
volatile long ticksFL = 0;
volatile long ticksFR = 0;
volatile long ticksRL = 0;
volatile long ticksRR = 0;

// --- Per-Wheel PID & Movement Control ---
struct WheelPID {
float Kp = 1.0, Ki = 0.0, Kd = 0.0;
  float integral = 0;
  float last_error = 0;
  long start_ticks = 0;
  long target_ticks = 0;
  bool active = false;
};

WheelPID pidFL, pidFR, pidRL, pidRR;
bool move_active = false;

//Wheel-Dimensions Globals
float wheel_diameter_cm = 3.81;  // 1.5 inch in cm
int encoder_ticks_per_rev = 520;
float total_distance_cm = 0;
int last_ticks_sum = 0;
int current_angle = 0;


// --------- Encoder ISRs with Direction Detection ---------
void encFL_ISR() {
  if (digitalRead(FL_ENC_A) == digitalRead(FL_ENC_B))
    ticksFL++;
  else
    ticksFL--;
}

void encFR_ISR() {
  if (digitalRead(FR_ENC_A) == digitalRead(FR_ENC_B))
    ticksFR++;
  else
    ticksFR--;
}

void encRL_ISR() {
  if (digitalRead(RL_ENC_A) == digitalRead(RL_ENC_B))
    ticksRL++;
  else
    ticksRL--;
}

void encRR_ISR() {
  if (digitalRead(RR_ENC_A) == digitalRead(RR_ENC_B))
    ticksRR++;
  else
    ticksRR--;
}


WiFiServer server(80);
int speedVal = 200;
String currentState = "Stopped";

Servo servoBase, servoLeft, servoRight, servoGrip;

void setup() {
  Serial.begin(115200);

  // OLED Display Setup
  //Wire.setSDA(OLED_SDA);
  //Wire.setSCL(OLED_SCL);
  //Wire.begin();
  
  if(!display.begin(OLED_I2C_ADDRESS, true)) {
    Serial.println(F("SH1106 allocation failed"));
  } else {
    display.clearDisplay();
    display.setTextSize(2);
    display.setTextColor(SH110X_WHITE);
    display.setCursor(0, 10);
    display.println("Searching...");
    display.display();
  }

  // Setup motor control pins
  pinMode(AIN1, OUTPUT); pinMode(AIN2, OUTPUT); pinMode(PWMA, OUTPUT);
  pinMode(BIN1, OUTPUT); pinMode(BIN2, OUTPUT); pinMode(PWMB, OUTPUT);
  pinMode(CIN1, OUTPUT); pinMode(CIN2, OUTPUT); pinMode(PWMC, OUTPUT);
  pinMode(DIN1, OUTPUT); pinMode(DIN2, OUTPUT); pinMode(PWMD, OUTPUT);
//  pinMode(STBY, OUTPUT); digitalWrite(STBY, HIGH);
  pinMode(LED_BUILTIN, OUTPUT);

 // Encoder Pins as Input
pinMode(FL_ENC_A, INPUT_PULLUP); pinMode(FL_ENC_B, INPUT_PULLUP);
pinMode(FR_ENC_A, INPUT_PULLUP); pinMode(FR_ENC_B, INPUT_PULLUP);
pinMode(RL_ENC_A, INPUT_PULLUP); pinMode(RL_ENC_B, INPUT_PULLUP);
pinMode(RR_ENC_A, INPUT_PULLUP); pinMode(RR_ENC_B, INPUT_PULLUP);

// Attach interrupts to Channel A of each encoder
attachInterrupt(digitalPinToInterrupt(FL_ENC_A), encFL_ISR, RISING);
attachInterrupt(digitalPinToInterrupt(FR_ENC_A), encFR_ISR, RISING);
attachInterrupt(digitalPinToInterrupt(RL_ENC_A), encRL_ISR, RISING);
attachInterrupt(digitalPinToInterrupt(RR_ENC_A), encRR_ISR, RISING);

  // Attach servos to their GPIO pins
  servoBase.attach(9);
  servoLeft.attach(8);
  servoRight.attach(27);
  servoGrip.attach(28);

  // --- Smart WiFi Connection ---
  bool connected = false;
  for (int i = 0; i < numNetworks; i++) {
    // Update display to show current attempt
    display.clearDisplay();
    display.setTextSize(1);
    display.setCursor(0, 10);
    display.println("Trying:");
    display.setTextSize(2);
    display.setCursor(0, 25);
    display.println(knownNetworks[i].ssid);
    display.display();
    
    WiFi.begin(knownNetworks[i].ssid, knownNetworks[i].password);
    Serial.print("\nAttempting to connect to ");
    Serial.println(knownNetworks[i].ssid);

    // Wait for connection with a 7-second timeout
    unsigned long startAttemptTime = millis();
    while (WiFi.status() != WL_CONNECTED && millis() - startAttemptTime < 7000) {
      delay(500);
      Serial.print(".");
    }

    // If connected, break the loop
    if (WiFi.status() == WL_CONNECTED) {
      connected = true;
      break;
    } else {
      Serial.println("\nFailed to connect.");
      WiFi.disconnect(true); // Disconnect and try next network
      delay(100);
    }
  }

  // Final status update on display
  display.clearDisplay();
  display.setCursor(0,0);
  if (connected) {
    Serial.println("\nWiFi connected.");
    Serial.print("IP address: "); Serial.println(WiFi.localIP());
    Serial.print("SSID: "); Serial.println(WiFi.SSID());
    
    display.setTextSize(2);
    display.println("Connected!");
    display.setTextSize(1);
    display.setCursor(0, 20);
    display.print("IP: ");
    display.println(WiFi.localIP());
    display.setCursor(0, 32);
    display.print("SSID: ");
    display.println(WiFi.SSID());
  } else {
    Serial.println("\nCould not connect to any WiFi network.");
    display.setTextSize(2);
    display.println("Connection");
    display.println("Failed");
  }
  display.display();


  // Connect to Wi-Fi
  // WiFi.begin(ssid, password);
  // while (WiFi.status() != WL_CONNECTED) {
  //   delay(500); Serial.print(".");
  //   display.print(".");
  //   display.display();
  // }

  // Serial.println("\nWiFi connected.");
  // Serial.print("IP address: "); Serial.println(WiFi.localIP());

  // // Update OLED
  // display.clearDisplay();
  // display.setCursor(0,0);
  // display.setTextSize(2);
  // display.println("Connected!");
  // display.setTextSize(1);
  // display.setCursor(0, 20);
  // display.print("IP Address:");
  // display.setCursor(0, 30);
  // display.print(WiFi.localIP());
  // display.display();

  server.begin();
}

void loop() {
  // --- OLED Heartbeat ---
  // Toggles a pixel in the top-right corner to show the Pico is running.
  if (millis() - lastHeartbeatMillis > 500) {
    lastHeartbeatMillis = millis();
    heartbeatState = !heartbeatState;
    display.fillRect(DISPLAY_WIDTH - 3, 0, 3, 3, heartbeatState ? SH110X_WHITE : SH110X_BLACK);
    display.display();
  }
  
  WiFiClient client = server.available();
  updateDistanceMoved();

  if (move_active) {
    updateAllWheelPIDs();
}

  if (client) {
    Serial.println("\nClient connected");

    String request = client.readStringUntil('\r');
    client.flush();
    Serial.print("Request: "); Serial.println(request);

    if (request.indexOf("/servo?") != -1) {
      if (request.indexOf("base=") != -1) {
        int val = request.substring(request.indexOf("base=") + 5).toInt();
        servoBase.write(constrain(val, 0, 180));
      } else if (request.indexOf("left=") != -1) {
        int val = request.substring(request.indexOf("left=") + 5).toInt();
        servoLeft.write(constrain(val, 0, 120));
      } else if (request.indexOf("right=") != -1) {
        int val = request.substring(request.indexOf("right=") + 6).toInt();
        servoRight.write(constrain(val, 70, 180));
      } else if (request.indexOf("grip=") != -1) {
        int val = request.substring(request.indexOf("grip=") + 5).toInt();
        servoGrip.write(constrain(val, 0, 120));
      }
      client.println("HTTP/1.1 200 OK");
      client.println("Content-Type: text/plain");
      client.println();
      client.print("OK");
      return;
    }
    else if (request.indexOf("/move_rt?") != -1) {
      float dist = request.substring(request.indexOf("dist=") + 5, request.indexOf("&")).toFloat();
      float angle = request.substring(request.indexOf("angle=") + 6).toFloat();
      startMoveRT(dist, angle);
    }
    else if (request.indexOf("/move_xy?") != -1) {
      float x = request.substring(request.indexOf("x=") + 2, request.indexOf("&")).toFloat();
      float y = request.substring(request.indexOf("y=") + 2).toFloat();
      startMoveXY(x, y);
    }
    else if (request.indexOf("/stop_all_move") != -1) {
      stopAllMove();
    }
    else if (request.indexOf("/set_pid?") != -1) {
       // Example: /set_pid?wheel=fl&p=1.2&i=0.1&d=0.3
      String wheel = request.substring(request.indexOf("wheel=") + 6, request.indexOf("&"));
      float p = request.substring(request.indexOf("p=") + 2, request.indexOf("&", request.indexOf("p="))).toFloat();
      float i = request.substring(request.indexOf("i=") + 2, request.indexOf("&", request.indexOf("i="))).toFloat();
      float d = request.substring(request.indexOf("d=") + 2).toFloat();
      
      if (wheel == "fl") { pidFL.Kp = p; pidFL.Ki = i; pidFL.Kd = d; }
      else if (wheel == "fr") { pidFR.Kp = p; pidFR.Ki = i; pidFR.Kd = d; }
      else if (wheel == "rl") { pidRL.Kp = p; pidRL.Ki = i; pidRL.Kd = d; }
      else if (wheel == "rr") { pidRR.Kp = p; pidRR.Ki = i; pidRR.Kd = d; }
    }
    else if (request.indexOf("/vector") != -1) {
      int angleStart = request.indexOf("angle=") + 6;
int forceStart = request.indexOf("force=") + 6;
int ampIndex = request.indexOf('&');

int angle = 0;
float force = 0;

if (angleStart > 5 && forceStart > 5) {
  if (angleStart < forceStart) {
    angle = request.substring(angleStart, ampIndex).toInt();
    force = request.substring(forceStart).toFloat();
  } else {
    force = request.substring(forceStart, ampIndex).toFloat();
    angle = request.substring(angleStart).toInt();
  }
}


      int dynamicSpeed = int(constrain(force * 255, 0, 255));
      handleAnalogDirection(angle, dynamicSpeed);
    }
    else if (request.indexOf("/FL") != -1) moveForwardLeft(speedVal);
    else if (request.indexOf("/FR") != -1) moveForwardRight(speedVal);
    else if (request.indexOf("/F") != -1) moveForward(speedVal);
    else if (request.indexOf("/BL") != -1) moveBackwardLeft(speedVal);
    else if (request.indexOf("/BR") != -1) moveBackwardRight(speedVal);
    else if (request.indexOf("/CW") != -1) rotateCW(speedVal);
    else if (request.indexOf("/CCW") != -1) rotateCCW(speedVal);
    else if (request.indexOf("/B") != -1) moveBackward(speedVal);
    else if (request.indexOf("/L") != -1) moveLeft(speedVal);
    else if (request.indexOf("/R") != -1) moveRight(speedVal);
    else if (request.indexOf("/S") != -1) stopBot();
    else if (request.indexOf("/reset_encoders") != -1) {
      ticksFL = 0;
      ticksFR = 0;
      ticksRL = 0;
      ticksRR = 0;
      Serial.println("Encoders reset.");
    }

    else if (request.indexOf("/speed=") != -1) {
      int val = request.substring(request.indexOf('=') + 1).toInt();
      speedVal = constrain(val, 0, 255);
      Serial.print("Speed set to: "); Serial.println(speedVal);
    }
    else if (request.indexOf("/reset_distance") != -1) {
      total_distance_cm = 0;
      last_ticks_sum = abs(ticksFL) + abs(ticksFR) + abs(ticksRL) + abs(ticksRR);
      Serial.println("Distance reset.");
    }
    else if (request.indexOf("/status") != -1) {
      
      client.println("HTTP/1.1 200 OK");
      client.println("Content-Type: application/json");
      client.println();
      client.print("{"
  "\"state\":\"" + currentState + "\","
  "\"speed\":" + String(speedVal) + ","
  "\"fl\":" + String(ticksFL) + ","
  "\"fr\":" + String(ticksFR) + ","
  "\"rl\":" + String(ticksRL) + ","
  "\"rr\":" + String(ticksRR) + ","
  "\"angle\":" + String(current_angle) + ","
  "\"distance\":" + String(total_distance_cm, 2) +
"}");


      return;
    }

    client.println("HTTP/1.1 200 OK");
    client.println("Content-type:text/html\r\n\r\n");
    sendWebPage(client);
  }
}



void blinkLED() {
  digitalWrite(LED_BUILTIN, HIGH);
  delay(50);
  digitalWrite(LED_BUILTIN, LOW);
}

// Move Forward: Bot moves straight ahead ↑
// A (FL), B (FR), C (RL), D (RR) => All Forward
void moveForward(int spd) {
  currentState = "Moving Forward";
  Serial.println(currentState);

  // Motor A (Front Left)
  digitalWrite(AIN1, HIGH); digitalWrite(AIN2, LOW); analogWrite(PWMA, spd);

  // Motor B (Front Right)
  digitalWrite(BIN1, HIGH); digitalWrite(BIN2, LOW); analogWrite(PWMB, spd);

  // Motor C (Rear Left)
  digitalWrite(CIN1, HIGH); digitalWrite(CIN2, LOW); analogWrite(PWMC, spd);

  // Motor D (Rear Right)
  digitalWrite(DIN1, HIGH); digitalWrite(DIN2, LOW); analogWrite(PWMD, spd);

  blinkLED();
}

// Move Backward: Bot moves straight backward ↓
// A, B, C, D => All Backward
void moveBackward(int spd) {
  currentState = "Moving Backward";
  Serial.println(currentState);

  // Motor A (Front Left)
  digitalWrite(AIN1, LOW); digitalWrite(AIN2, HIGH); analogWrite(PWMA, spd);

  // Motor B (Front Right)
  digitalWrite(BIN1, LOW); digitalWrite(BIN2, HIGH); analogWrite(PWMB, spd);

  // Motor C (Rear Left)
  digitalWrite(CIN1, LOW); digitalWrite(CIN2, HIGH); analogWrite(PWMC, spd);

  // Motor D (Rear Right)
  digitalWrite(DIN1, LOW); digitalWrite(DIN2, HIGH); analogWrite(PWMD, spd);

  blinkLED();
}

// Move Left: Bot strafes left ←
// A (FL) & D (RR) => Backward
// B (FR) & C (RL) => Forward
void moveLeft(int spd) {
  currentState = "Moving Left";
  Serial.println(currentState);

  // Motor A (Front Left)
  digitalWrite(AIN1, LOW); digitalWrite(AIN2, HIGH); analogWrite(PWMA, spd);

  // Motor B (Front Right)
  digitalWrite(BIN1, HIGH); digitalWrite(BIN2, LOW); analogWrite(PWMB, spd);

  // Motor C (Rear Left)
  digitalWrite(CIN1, HIGH); digitalWrite(CIN2, LOW); analogWrite(PWMC, spd);

  // Motor D (Rear Right)
  digitalWrite(DIN1, LOW); digitalWrite(DIN2, HIGH); analogWrite(PWMD, spd);

  blinkLED();
}

// Move Right: Bot strafes right →
// A (FL) & D (RR) => Forward
// B (FR) & C (RL) => Backward
void moveRight(int spd) {
  currentState = "Moving Right";
  Serial.println(currentState);

  // Motor A (Front Left)
  digitalWrite(AIN1, HIGH); digitalWrite(AIN2, LOW); analogWrite(PWMA, spd);

  // Motor B (Front Right)
  digitalWrite(BIN1, LOW); digitalWrite(BIN2, HIGH); analogWrite(PWMB, spd);

  // Motor C (Rear Left)
  digitalWrite(CIN1, LOW); digitalWrite(CIN2, HIGH); analogWrite(PWMC, spd);

  // Motor D (Rear Right)
  digitalWrite(DIN1, HIGH); digitalWrite(DIN2, LOW); analogWrite(PWMD, spd);

  blinkLED();
}

// Rotate Clockwise: Left motors forward, right motors backward ↻
void rotateCW(int spd) {
  currentState = "Rotating Clockwise";
  Serial.println(currentState);

  // Motor A (FL) forward
  digitalWrite(AIN1, HIGH); digitalWrite(AIN2, LOW); analogWrite(PWMA, spd);

  // Motor B (FR) backward
  digitalWrite(BIN1, LOW); digitalWrite(BIN2, HIGH); analogWrite(PWMB, spd);

  // Motor C (RL) forward
  digitalWrite(CIN1, HIGH); digitalWrite(CIN2, LOW); analogWrite(PWMC, spd);

  // Motor D (RR) backward
  digitalWrite(DIN1, LOW); digitalWrite(DIN2, HIGH); analogWrite(PWMD, spd);

  blinkLED();
}

// Rotate Counterclockwise: Left motors backward, right motors forward ↺
void rotateCCW(int spd) {
  currentState = "Rotating Counterclockwise";
  Serial.println(currentState);

  // Motor A (FL) backward
  digitalWrite(AIN1, LOW); digitalWrite(AIN2, HIGH); analogWrite(PWMA, spd);

  // Motor B (FR) forward
  digitalWrite(BIN1, HIGH); digitalWrite(BIN2, LOW); analogWrite(PWMB, spd);

  // Motor C (RL) backward
  digitalWrite(CIN1, LOW); digitalWrite(CIN2, HIGH); analogWrite(PWMC, spd);

  // Motor D (RR) forward
  digitalWrite(DIN1, HIGH); digitalWrite(DIN2, LOW); analogWrite(PWMD, spd);

  blinkLED();
}

// Move Forward Left (↖): A & C forward, others off
// Move Forward Left (↖): A (FL) backward, B (FR) forward, C (RL) forward, D (RR) off
void moveForwardLeft(int spd) {
  currentState = "Moving Forward Left";
  Serial.println(currentState);

  // Motor A (FL) BACKWARD
  digitalWrite(AIN1, LOW); digitalWrite(AIN2, LOW); analogWrite(PWMA, spd);

  // Motor B (FR) FORWARD
  digitalWrite(BIN1, HIGH); digitalWrite(BIN2, LOW); analogWrite(PWMB, spd);

  // Motor C (RL) FORWARD
  digitalWrite(CIN1, HIGH); digitalWrite(CIN2, LOW); analogWrite(PWMC, spd);

  // Motor D (RR) OFF
  digitalWrite(DIN1, LOW); digitalWrite(DIN2, LOW); analogWrite(PWMD, 0);

  blinkLED();
}


// Move Forward Right (↗): A (FL) forward, B (FR) backward, D (RR) forward, C (RL) off
void moveForwardRight(int spd) {
  currentState = "Moving Forward Right";
  Serial.println(currentState);

  // Motor A (FL) FORWARD
  digitalWrite(AIN1, HIGH); digitalWrite(AIN2, LOW); analogWrite(PWMA, spd);

  // Motor B (FR) BACKWARD
  digitalWrite(BIN1, LOW); digitalWrite(BIN2, LOW); analogWrite(PWMB, spd);

  // Motor D (RR) FORWARD
  digitalWrite(DIN1, HIGH); digitalWrite(DIN2, LOW); analogWrite(PWMD, spd);

  // Motor C (RL) OFF
  digitalWrite(CIN1, LOW); digitalWrite(CIN2, LOW); analogWrite(PWMC, 0);

  blinkLED();
}


// Move Backward Left (↙): A & D backward, others off
void moveBackwardLeft(int spd) {
  currentState = "Moving Backward Left";
  Serial.println(currentState);

  // Motor A (FL)
  digitalWrite(AIN1, LOW); digitalWrite(AIN2, HIGH); analogWrite(PWMA, spd);

  // Motor D (RR)
  digitalWrite(DIN1, LOW); digitalWrite(DIN2, HIGH); analogWrite(PWMD, spd);

  // B & C off
  digitalWrite(BIN1, LOW); digitalWrite(BIN2, LOW); analogWrite(PWMB, 0);
  digitalWrite(CIN1, LOW); digitalWrite(CIN2, LOW); analogWrite(PWMC, 0);

  blinkLED();
}

// Move Backward Right (↘): B & C backward, others off
void moveBackwardRight(int spd) {
  currentState = "Moving Backward Right";
  Serial.println(currentState);

  // Motor B (FR)
  digitalWrite(BIN1, LOW); digitalWrite(BIN2, HIGH); analogWrite(PWMB, spd);

  // Motor C (RL)
  digitalWrite(CIN1, LOW); digitalWrite(CIN2, HIGH); analogWrite(PWMC, spd);

  // A & D off
  digitalWrite(AIN1, LOW); digitalWrite(AIN2, LOW); analogWrite(PWMA, 0);
  digitalWrite(DIN1, LOW); digitalWrite(DIN2, LOW); analogWrite(PWMD, 0);

  blinkLED();
}


// Stop: Disable all motors
void stopBot() {
  currentState = "Stopped";
  Serial.println(currentState);
  
  // Front Left Motor
  digitalWrite(AIN1, LOW);
  digitalWrite(AIN2, LOW);
  analogWrite(PWMA, 0);

  // Front Right Motor
  digitalWrite(BIN1, LOW);
  digitalWrite(BIN2, LOW);
  analogWrite(PWMB, 0);

  // Rear Left Motor
  digitalWrite(CIN1, LOW);
  digitalWrite(CIN2, LOW);
  analogWrite(PWMC, 0);

  // Rear Right Motor
  digitalWrite(DIN1, LOW);
  digitalWrite(DIN2, LOW);
  analogWrite(PWMD, 0);
}

void handleAnalogDirection(int angle, int spd) {
  currentState = "Analog Joystick Movement";

  if (angle >= 337 || angle < 22) {
    moveForward(spd);
  } else if (angle >= 22 && angle < 67) {
    moveForwardRight(spd);
  } else if (angle >= 67 && angle < 112) {
    moveRight(spd);
  } else if (angle >= 112 && angle < 157) {
    moveBackwardRight(spd);
  } else if (angle >= 157 && angle < 202) {
    moveBackward(spd);
  } else if (angle >= 202 && angle < 247) {
    moveBackwardLeft(spd);
  } else if (angle >= 247 && angle < 292) {
    moveLeft(spd);
  } else if (angle >= 292 && angle < 337) {
    moveForwardLeft(spd);
  }
  current_angle = angle;
}

void updateDistanceMoved() {
  int total_ticks = abs(ticksFL) + abs(ticksFR) + abs(ticksRL) + abs(ticksRR);
  int delta_ticks = total_ticks - last_ticks_sum;

  float k = 0.65 + (0.90 - 0.65) * abs(cos(2 * current_angle * PI / 180.0)); // k(θ)
  float cm_per_tick = (PI * wheel_diameter_cm / encoder_ticks_per_rev) * k;
  total_distance_cm += (delta_ticks / 4.0) * cm_per_tick;

  last_ticks_sum = total_ticks;
}
  
// --- New Per-Wheel PID Control Functions ---
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

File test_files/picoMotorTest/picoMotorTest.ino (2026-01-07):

// Motor A (Front Left)
#define AIN1 2
#define AIN2 3
#define PWMA 4

// Motor B (Front Right)
#define BIN1 5
#define BIN2 6
#define PWMB 7

// Motor C (Rear Left)
#define CIN1 10
#define CIN2 11
#define PWMC 12

// Motor D (Rear Right)
#define DIN1 13
#define DIN2 14
#define PWMD 15

#define STBY 8
#define LED_BUILTIN 25

int speedVal = 255;

void setup() {
  Serial.begin(115200);

  pinMode(AIN1, OUTPUT); pinMode(AIN2, OUTPUT); pinMode(PWMA, OUTPUT);
  pinMode(BIN1, OUTPUT); pinMode(BIN2, OUTPUT); pinMode(PWMB, OUTPUT);
  pinMode(CIN1, OUTPUT); pinMode(CIN2, OUTPUT); pinMode(PWMC, OUTPUT);
  pinMode(DIN1, OUTPUT); pinMode(DIN2, OUTPUT); pinMode(PWMD, OUTPUT);
  pinMode(STBY, OUTPUT); pinMode(LED_BUILTIN, OUTPUT);

  digitalWrite(STBY, HIGH);
  Serial.println("Motor Test Starting in 2s...");
  delay(2000);
}

void loop() {
  Serial.println("Spinning all motors FORWARD");
  digitalWrite(LED_BUILTIN, HIGH);
  
  // Forward
  digitalWrite(AIN1, HIGH); digitalWrite(AIN2, LOW); analogWrite(PWMA, speedVal);
  digitalWrite(BIN1, HIGH); digitalWrite(BIN2, LOW); analogWrite(PWMB, speedVal);
  digitalWrite(CIN1, HIGH); digitalWrite(CIN2, LOW); analogWrite(PWMC, speedVal);
  digitalWrite(DIN1, HIGH); digitalWrite(DIN2, LOW); analogWrite(PWMD, speedVal);

  delay(2000);

  Serial.println("Spinning all motors BACKWARD");
  digitalWrite(LED_BUILTIN, LOW);
  
  // Backward
  digitalWrite(AIN1, LOW); digitalWrite(AIN2, HIGH); analogWrite(PWMA, speedVal);
  digitalWrite(BIN1, LOW); digitalWrite(BIN2, HIGH); analogWrite(PWMB, speedVal);
  digitalWrite(CIN1, LOW); digitalWrite(CIN2, HIGH); analogWrite(PWMC, speedVal);
  digitalWrite(DIN1, LOW); digitalWrite(DIN2, HIGH); analogWrite(PWMD, speedVal);

  delay(2000);

  Serial.println("Stopping all motors");
  
  // Stop all
  digitalWrite(AIN1, LOW); digitalWrite(AIN2, LOW); analogWrite(PWMA, 0);
  digitalWrite(BIN1, LOW); digitalWrite(BIN2, LOW); analogWrite(PWMB, 0);
  digitalWrite(CIN1, LOW); digitalWrite(CIN2, LOW); analogWrite(PWMC, 0);
  digitalWrite(DIN1, LOW); digitalWrite(DIN2, LOW); analogWrite(PWMD, 0);

  delay(3000); // Wait before next cycle
}
